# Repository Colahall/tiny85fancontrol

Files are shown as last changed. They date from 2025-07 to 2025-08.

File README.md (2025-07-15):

# Tiny85FanControl







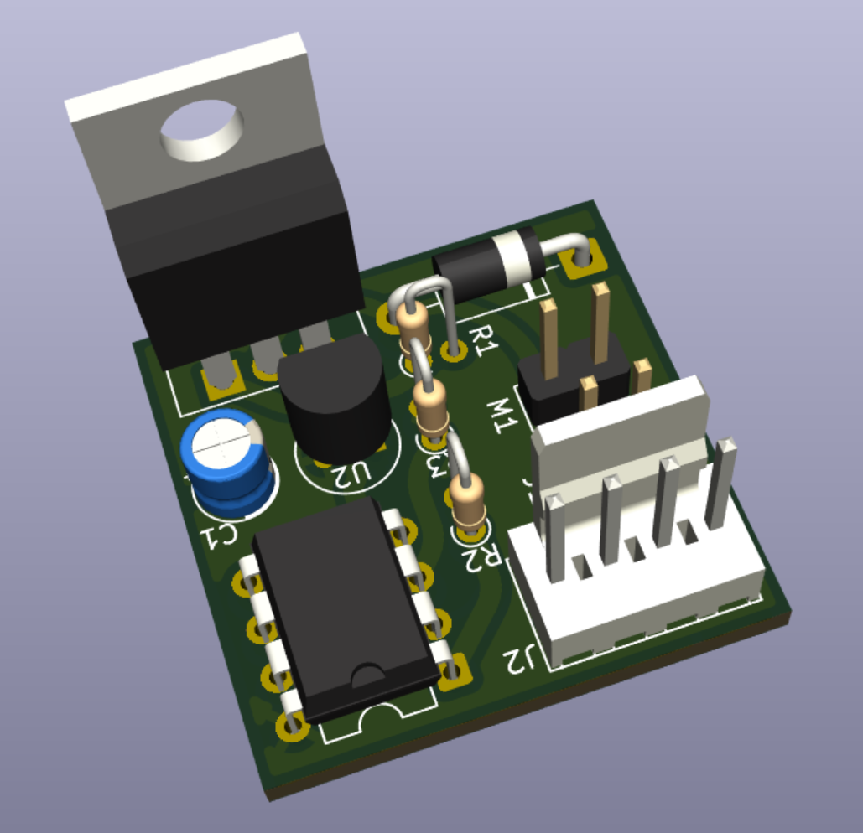
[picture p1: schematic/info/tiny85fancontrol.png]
Tiny85FanControl


A temperature-controlled fan system powered by an [ATtiny85](https://www.microchip.com/en-us/product/attiny85) and a [DS18B20](https://www.analog.com/media/en/technical-documentation/data-sheets/ds18b20.pdf) temperature sensor.

> ⚠️ This project is a **work in progress** and may not yet be suitable for all use cases.

## Hardware Requirements

You'll need the following components:

- [ATtiny85](https://www.microchip.com/en-us/product/attiny85) microcontroller
- [USBtinyISP](https://www.flashtree.com/products/11802) (or compatible ISP programmer)
- [DS18B20](https://www.analog.com/media/en/technical-documentation/data-sheets/ds18b20.pdf) 1-Wire temperature sensor
- Passive components (resistors, capacitors, etc.)

Refer to the [Bill of Materials (BOM)](schematic/info/tiny85fancontrol-bom.csv) for part numbers and quantities.

## Software Setup

### Ubuntu 24.04 LTS

```bash
sudo apt-get install build-essential avrdude gcc-avr binutils-avr avr-libc git
````

### Fedora 42

```bash
sudo dnf install avrdude avr-gcc avr-libc git
```

### macOS (via [Homebrew](https://brew.sh/))

```bash
brew tap osx-cross/avr
brew install avr-gcc avrdude git
```

### Windows

Use [WSL](https://docs.microsoft.com/en-us/windows/wsl/install) and follow the **Ubuntu** instructions inside your Linux environment.

## Building and uploading

To build this project, run `make` in the root directory of the project.

```bash
cd /path/to/project/

make        # Builds the binary
make fuse   # Fuses the chip with the configuration
make flash  # Uploads to the ATtiny85 via USBtinyISP
```

## Project Status

This project is working well for my needs, but there are still some things that could be improved.

Feel free to open an issue or submit a pull request if you have any ideas for improvements!

## Contributing

Pull requests and issues are welcome! If you’ve got a feature idea or fix, feel free to:

1. Fork this repo
2. Create a feature branch
3. Push and open a pull request

Please follow the existing code style and structure where possible.

## License

This project is licensed under the [MIT License](LICENSE).

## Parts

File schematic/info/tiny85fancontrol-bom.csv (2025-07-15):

Reference | Qty | Value | DNP | Exclude from BOM | Exclude from Board | Footprint | Datasheet
C1 | 1 | 0.1u |  |  |  | Capacitor_THT:CP_Radial_D4.0mm_P2.00mm | ~
D1 | 1 | 1N4001 |  |  |  | Diode_THT:D_DO-41_SOD81_P10.16mm_Horizontal | http://www.vishay.com/docs/88503/1n4001.pdf
J1 | 1 | UART_DBG |  |  |  | Connector_PinHeader_2.54mm:PinHeader_1x02_P2.54mm_Vertical | ~
J2 | 1 | Molex |  |  |  | Connector_Molex:Molex_KK-254_AE-6410-04A_1x04_P2.54mm_Vertical | ~
M1 | 1 | Fan |  |  |  | Connector_PinHeader_2.54mm:PinHeader_1x02_P2.54mm_Vertical | ~
Q1 | 1 | IRF3808 |  |  |  | Package_TO_SOT_THT:TO-220-3_Vertical | http://www.irf.com/product-info/datasheets/data/irf3205.pdf
R1 | 1 | 10k |  |  |  | Resistor_THT:R_Axial_DIN0204_L3.6mm_D1.6mm_P1.90mm_Vertical | ~
R2 | 1 | 100R |  |  |  | Resistor_THT:R_Axial_DIN0204_L3.6mm_D1.6mm_P1.90mm_Vertical | ~
R3 | 1 | 4.7k |  |  |  | Resistor_THT:R_Axial_DIN0204_L3.6mm_D1.6mm_P1.90mm_Vertical | ~
U1 | 1 | ATtiny85-20P |  |  |  | Package_DIP:DIP-8_W7.62mm | http://ww1.microchip.com/downloads/en/DeviceDoc/atmel-2586-avr-8-bit-microcontroller-attiny25-attiny45-attiny85_datasheet.pdf
U2 | 1 | DS18B20 |  |  |  | Package_TO_SOT_THT:TO-92_Inline | http://datasheets.maximintegrated.com/en/ds/DS18B20.pdf

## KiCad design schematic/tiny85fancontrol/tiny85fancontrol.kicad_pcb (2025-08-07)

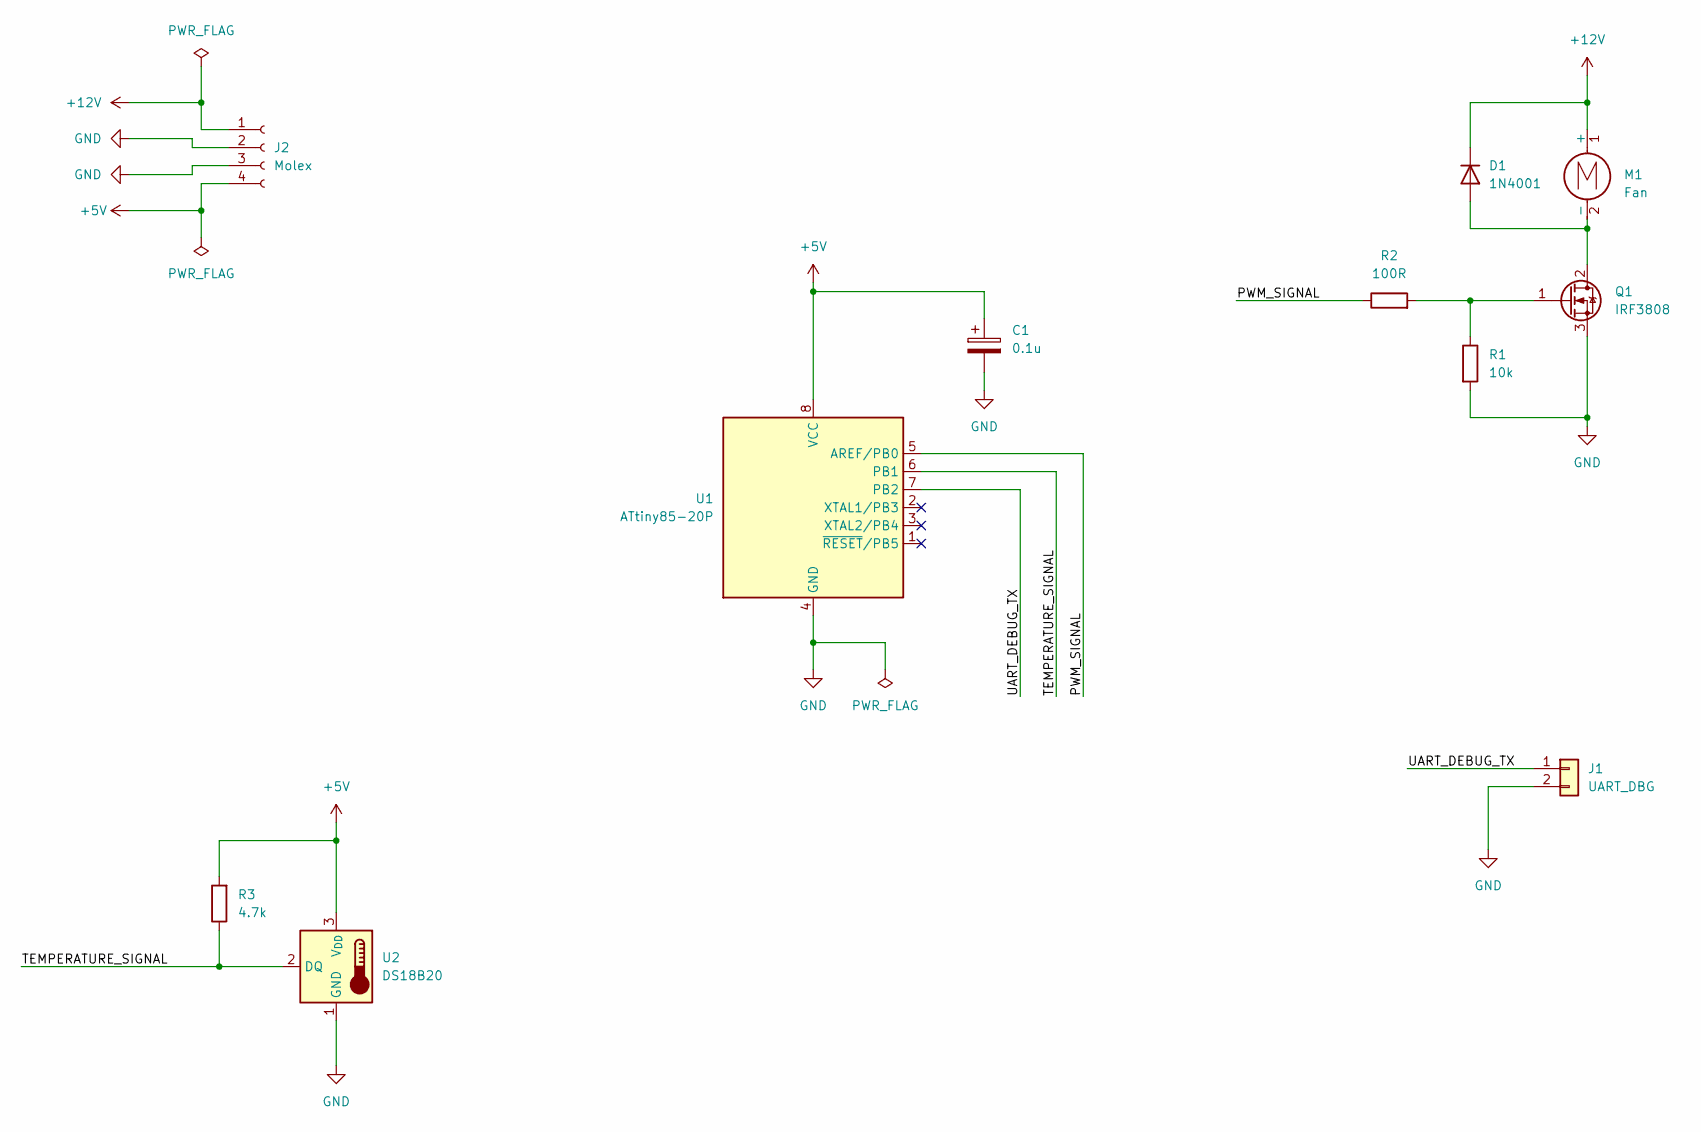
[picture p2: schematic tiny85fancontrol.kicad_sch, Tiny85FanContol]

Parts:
C1: 0.1u; CP_Radial_D4.0mm_P2.00mm
D1: 1N4001; D_DO-41_SOD81_P10.16mm_Horizontal
J1: UART_DBG; PinHeader_1x02_P2.54mm_Vertical
J2: Molex; Molex_KK-254_AE-6410-04A_1x04_P2.54mm_Vertical
M1: Fan; PinHeader_1x02_P2.54mm_Vertical
Q1: IRF3808; TO-220-3_Vertical
R1: 10k; R_Axial_DIN0204_L3.6mm_D1.6mm_P1.90mm_Vertical
R2: 100R; R_Axial_DIN0204_L3.6mm_D1.6mm_P1.90mm_Vertical
R3: 4.7k; R_Axial_DIN0204_L3.6mm_D1.6mm_P1.90mm_Vertical
U1: ATtiny85-20P; DIP-8_W7.62mm
U2: DS18B20; TO-92_Inline

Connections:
+5V: C1.1, J2.4, R3.2, U1.8 (VCC), U2.3 (V_{DD})
+12V: D1.1 (K), J2.1, M1.1 (+)
/PWM_SIGNAL: R2.1, U1.5 (AREF/PB0)
/TEMPERATURE_SIGNAL: R3.1, U1.6 (PB1), U2.2 (DQ)
/UART_DEBUG_TX: J1.1, U1.7 (PB2)
GND: C1.2, J1.2, J2.2, J2.3, Q1.3 (S), R1.2, U1.4 (GND), U2.1 (GND)
unnamed: D1.2 (A), M1.2 (-), Q1.2 (D)
unnamed: Q1.1 (G), R1.1, R2.2

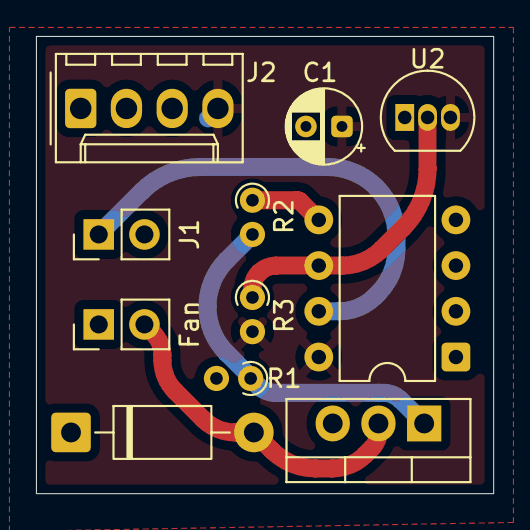
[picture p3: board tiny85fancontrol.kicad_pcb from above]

Board: 2 copper layers, 25.4 x 25.4 mm, 11 parts (0 on the bottom side), 8 nets.

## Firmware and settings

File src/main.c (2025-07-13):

/*
 * Copyright (c) 2025 Colahall, LLC.
 *
 * This File is part of Tiny85FanControl (see https://colahall.io/).
 *
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
 */

#include "ds18b20.h"
#include "pwm.h"
#include "fan_curve.h"
#include "temp_sensor.h"
#include "uart.h"

#include <avr/io.h>
#include <util/delay.h>

#define BUILD_VERSION "1.0.0"

int main(void) {
  pwm_init();         // Initialize PWM
  uart_init();        // Initialize UART
  temp_sensor_init(); // Initialize temperature sensor

  uart_print("Tiny85 Fan Control (Table LERP)\r\n");
  uart_print("Build Version: " BUILD_VERSION "\r\n");
  uart_print("System Initialized\r\n");

  uint8_t current_pwm_duty = 0;
  int16_t case_temp = 0;

  // Set the PWM to max duty cycle initially until fan ramps up
  pwm_set(255);
  _delay_ms(9999);

  for (;;) {
    case_temp = ds18b20_read_celsius();

    uart_print("Current Temp = ");
    uart_print_dec16(case_temp);
    uart_print(" C, ");

    current_pwm_duty = fan_curve_compute_pwm(case_temp);

    pwm_set(current_pwm_duty);
    uart_print("PWM Duty Cycle = ");
    uart_print_dec16(current_pwm_duty);
    uart_print("\r\n");

    _delay_ms(2000); // Delay for a longer period (e.g., 2 seconds)
  }

  return 0; // This line will never be reached
}

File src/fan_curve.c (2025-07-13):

/*
 * Copyright (c) 2025 Colahall, LLC.
 *
 * This File is part of Tiny85FanControl (see https://colahall.io/).
 *
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
 */

#include "fan_curve.h"

// Structure to define a point on the fan curve
typedef struct {
  int8_t temperature; // Temperature in Celsius (-85 to +125 C))
  uint8_t pwm_duty;   // PWM duty cycle (0-255)
} fan_curve_point_t;

// Define your fan curve points in a PROGMEM array to save RAM
// The points MUST be sorted by temperature in ascending order.
static const fan_curve_point_t fan_curve[] = {
    {25, 0},   // Example: Below 25C, fan is off
    {27, 128},  // At 27C, fan is quiet 50% duty cycle
    {30, 192}, // At 30C, fan starts to ramp up
    {35, 210}, // At 35C, fan starts to ramp up
    {40, 220}, // At 40C, fan is more audible
    {50, 230}, // At 50C and above, fan is at near full speed
    {60, 255}  // Ensure full speed is maintained even at higher temps
};

#define NUM_FAN_CURVE_POINTS (sizeof(fan_curve) / sizeof(fan_curve_point_t))

/**
 * Compute the PWM duty cycle based on the current temperature.
 *
 * @param temperature The current temperature in Celsius.
 * @return The computed PWM duty cycle (0-255).
 */
uint8_t fan_curve_compute_pwm(int16_t current_temp) {
  // If current_temp is below the first point, return 0 duty
  if (current_temp < fan_curve[0].temperature) {
    return fan_curve[0].pwm_duty;
  }

  // Find the two points between which to interpolate
  for (uint8_t i = 0; i < NUM_FAN_CURVE_POINTS - 1; i++) {
    const fan_curve_point_t *p1 = &fan_curve[i];
    const fan_curve_point_t *p2 = &fan_curve[i + 1];

    if (current_temp >= p1->temperature && current_temp < p2->temperature) {
      // Perform linear interpolation (LERP)
      // current_pwm = p1.pwm_duty + (current_temp - p1.temperature) *
      // (p2.pwm_duty - p1.pwm_duty) / (p2.temperature - p1.temperature)

      // Use long for calculations to prevent overflow
      int32_t temp_range = p2->temperature - p1->temperature;
      int32_t pwm_range = p2->pwm_duty - p1->pwm_duty;
      int32_t temp_offset = current_temp - p1->temperature;

      // Avoid division by zero if two points have the same temperature
      if (temp_range == 0) {
        // (shouldn't happen if sorted uniquely)
        return p1->pwm_duty;
      }

      int32_t interpolated_pwm =
          (int32_t)p1->pwm_duty + (temp_offset * pwm_range) / temp_range;

      // Clamp the result to 0-255 just in case
      if (interpolated_pwm > 255)
        return 255;
      if (interpolated_pwm < 0)
        return 0;

      return (uint8_t)interpolated_pwm;
    }
  }

  // Handle temperatures equal to or above the last point
  return fan_curve[NUM_FAN_CURVE_POINTS - 1].pwm_duty;
}

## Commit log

2025-07-10 1-Wire and Temp Sensor Complete
2025-07-10 Add PWM control and fan curve functionality
    - Implement PWM driver with initialization and duty cycle control.
    - Introduce fan curve logic for temperature-based PWM adjustments.
    - Update main application to utilize new PWM and fan curve features.
    - Include necessary header files and adjust UART definitions.
2025-07-13 Adjust fan curve for 12V
2025-07-13 Increase initial PWM duty cycle duration for fan ramp-up
2025-07-14 Add schematic and PCB
    [tiny85fancontrol.kicad_pcb, tiny85fancontrol.kicad_sch]
2025-07-14 Fix: Temperature sensor connected backwards
    Thanks to amdj at #kicad for spotting this issue
    [tiny85fancontrol.kicad_pcb, tiny85fancontrol.kicad_sch]
2025-07-15 Update README
    Update project description, hardware requirements, and software setup instructions
    Add BOM and PCB image
    [tiny85fancontrol-bom.csv]
2025-07-15 Add instruction to fuse the chip in README
2025-08-07 Update Schematic and PCB According to Reviews
    Placed temperature sensor away from MOSFET.
    Fixed PIN assignments according to software.
    [tiny85fancontrol.kicad_pcb, tiny85fancontrol.kicad_sch]

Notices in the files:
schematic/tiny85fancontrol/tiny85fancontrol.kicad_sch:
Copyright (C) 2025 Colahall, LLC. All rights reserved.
